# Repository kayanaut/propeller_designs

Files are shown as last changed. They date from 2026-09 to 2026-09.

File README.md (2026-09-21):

# Propeller Designs

A reference collection for propeller and thruster design: what each design type is for, how
to build it, and the geometry tables to build it from. Mostly marine, mostly small.

- [underwater_designs.md](underwater_designs.md) — thirteen marine propulsor types, what
  each is for, its typical parameter ranges, and where its geometry lives
- [aerial_designs.md](aerial_designs.md) — eleven air propeller and rotor types, the same way

## CAD prompts

- [cad/aerial_cad.md](cad/aerial_cad.md) — build briefs for the aerial designs
- [cad/underwater_cad.md](cad/underwater_cad.md) — build briefs for the underwater designs

## In this repo

- [cad/](cad/README.md) — 54 geometry tables across 24 design families, one folder per
  design, each with a `source-geometry.md` saying what data it needs and what has been found
- [cad/CONVENTIONS.md](cad/CONVENTIONS.md) — the datums: face pitch line, generator line,
  rake, skew and camber. The definitions the textbooks leave implicit, and that quietly
  break a blade when you get them wrong
- [formulas.md](formulas.md) — the working equations, each with the datum it assumes
- [cad/tools/](cad/tools/) — regenerate the tables (`make-geometry.py`), check them against
  the briefs' own rules (`check-geometry.py`), build a ducted propeller from them at any
  diameter (`build_ducted_kort.py --diameter 100`), and check an exported mesh is closed
  (`check_stl.py`)
- [projects/toroidal-rov-thruster/](projects/toroidal-rov-thruster/) — one design carried
  all the way through: parametric CAD, geometric checks and OpenFOAM cases, with its
  mistakes left visible

## Geometry creation

- [CadQuery](https://cadquery.readthedocs.io/) — Python parametric CAD on OCCT; the scripting tool the build briefs assume
- [Parametric Propeller CAD Generator](https://github.com/Andre-AH/Parametric-Propeller-CAD-Generator) — FreeCAD, blade count, diameter and angles driven from a spreadsheet
- [bladegen](https://github.com/tallakt/bladegen) — OpenSCAD blade generator
- [OpenVSP](https://github.com/nasa/OpenVSP) — NASA parametric geometry tool with a real propeller component: activity factor, feathering, folding
- [PropCad](https://www.hydrocompinc.com/solutions/propcad/) — marine propeller geometry from chord, thickness, skew and rake distributions
- [B-Series propeller generator](https://www.wageningen-b-series-propeller.com/) — Wageningen B geometry straight to STL or STEP
- [APC geometry files](https://www.apcprop.com/technical-information/file-downloads/) — `.peo` text files with real blade offsets for every APC size
- [UIUC airfoil coordinates](https://m-selig.ae.illinois.edu/ads/coord_database.html) — ~1,600 section coordinate sets; every blade loft starts here

## Data and tools

- [UIUC propeller database](https://m-selig.ae.illinois.edu/props/propDB.html) — measured low-Reynolds propeller performance
- [APC performance data](https://www.apcprop.com/technical-information/performance-data/) — computed curves for every APC size
- [XFOIL](https://web.mit.edu/drela/Public/web/xfoil/) — section polars at the low Reynolds numbers small blades actually run at
- [XROTOR](https://web.mit.edu/drela/Public/web/xrotor/) — lifting-line design and analysis for free-tip and ducted propellers
- [QPROP](https://web.mit.edu/drela/Public/web/qprop/) — propeller and motor as one system, for matching a blade to its drive
- [JBLADE](https://sites.google.com/site/joaomorgado23/downloads) — open-source BEM propeller design, coupled to XFOIL for polars
- [OpenProp](https://www.epps.com/openprop) — GPL lifting-line design code, used for AUV and ROV thrusters
- [JavaProp](https://www.mh-aerotools.de/airfoils/javaprop.htm) — free propeller design and analysis for small aircraft and boats
- [ITTC open water test procedure](https://www.ittc.info/media/9621/75-02-03-021.pdf) — how marine propeller performance is actually measured and reported
- [trimesh](https://trimesh.org/) — watertight and manifold checks on an exported mesh

*Links checked 2026-09-08.*

## Reading the data

Every table says where it came from, in its own header: transcribed from a cited source,
`GENERATED BY` a named script, or `SYNTHETIC` — invented to be dimensionally consistent with
a brief, and never to be mistaken for a real design. Where a source prints something
impossible or omits a table, that is recorded as a `DEFECT:` or `NOT IN SOURCE` note rather
than quietly patched; it is usually the reason the geometry is the way it is.

Nothing here has been physically built and tested, and no performance number in this
repository has been validated against a measurement.

## Licence

Code ([cad/tools/](cad/tools/), `projects/**/source/`) under [MIT](LICENSE); tables, briefs
and documentation under [CC BY 4.0](LICENSE-DATA). Transcribed and vendor material keeps the
terms of its own source and is not relicensed here — each file names it.

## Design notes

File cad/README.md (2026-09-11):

# CAD Models

Briefs: [aerial_cad.md](aerial_cad.md) · [underwater_cad.md](underwater_cad.md).
Datums: [CONVENTIONS.md](CONVENTIONS.md) — pitch line, generator line, rake and camber
definitions the briefs leave implicit. Every CSV repeats them in its own header, so a table
never has to be interpreted from memory.
Models: [underwater/](underwater/) · [aerial/](aerial/), one folder per design, each with a
`source-geometry.md` naming the data it needs and the CSVs holding what has been obtained.
Generated tables come from [tools/make-geometry.py](tools/make-geometry.py) (underwater) and
[tools/make-aerial-geometry.py](tools/make-aerial-geometry.py) — re-runnable, byte-identical,
each with its own rules checker. **The two domains do not share rules:** the 1 mm minimum
trailing-edge thickness is wet-specific and must never be applied to an aerial blade, which
wants a sharp TE. Provenance is marked per requirement: `SOURCED` (published table, cited),
`GENERATED` (published equation), `SYNTHETIC` (built here from the brief's own numbers — never
from a real series), `NOT SOURCED` (missing, with the reason). All 24 designs now have geometry. The five remaining
`NOT SOURCED` entries are real-source gaps a synthetic stand-in does not close — four marine
(B-series ×2, DTMB 4381–4384 offsets, Newton–Rader) and one aerial (NACA 6-series ordinates,
which are tabulated rather than equation-derived).

# **Built:** 
6 of 13 underwater, 0 of 11 aerial. All six are watertight and manifold.

- **[ducted-kort](underwater/ducted-kort/model.stl)** — *meets its brief.* Nozzle ID 250, Ø247
  `Z=4`, clearance 1.500 with zero deviation across the tip chord. Checked against real 19A
  ordinates ([source-geometry.md](underwater/ducted-kort/source-geometry.md)): wall is
  cylindrical over the sweep and the tip is square. Nothing outstanding.
- **[surface-piercing](underwater/surface-piercing/model.stl)** — *fix the planform.* The only
  single unioned solid in the set. Tip is tapered, not a square-cut cleaver. Ø285.6 vs 250.
- **[rim-driven](underwater/rim-driven/model.stl)** — *fix the duct.* Rotor correct and truly
  hubless. Duct is a bare annulus; magnets overlap the ring instead of sitting in pockets.
- **[contra-rotating](underwater/contra-rotating/model.stl)** — *delete one body.* Pair is correct
  and the mirror is genuine. A stray third propeller sits at `z=0` and clashes with the sleeve.
- **[pump-jet](underwater/pump-jet/model.stl)** — **rebuild.** Rotor cuts through the shroud by
  9.5 mm; stator sits inside the rotor, not up- or downstream; built on Y.
- **[supercavitating](underwater/supercavitating/model.stl)** — **rebuild.** Blades are detached —
  a 4.62 mm gap, nothing unioned. Ø297.7 vs 250.

# **Not built**

**underwater:** 
- FPP
- CPP
- Tip-loaded
- Skewed
- Toroidal
- Voith Schneider
- Podded azimuth

**aerial:** 
- Fixed-pitch
- Custom carbon
- Collective pitch
- eVTOL proprotor
- Folding
- Ducted fan
- Coaxial
- Q-tip
- Toroidal
- Serrated
- Cyclorotor.

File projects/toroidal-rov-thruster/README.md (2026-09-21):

# Toroidal ROV thruster

A ducted toroidal-bladed thruster for a small ROV, built around a
[Blue Robotics M200](https://bluerobotics.com/store/thrusters/motors/m200-motor-r1/) motor
and intended for resin printing. This is the repository's one complete design: carried from
parameters through CAD, geometric checks and CFD, with its mistakes left visible.

> **Status: UNVALIDATED.** Nothing here has been printed, and no thrust has ever been
> measured. The CFD numbers below come from a steady MRF run that was stopped before
> convergence, on one mesh, never compared with any measurement. Use them to compare
> options, not to predict performance.

## What is here

| Folder | What it is |
|---|---|
| [`toroidal_rov_prototype2A/thruster_proto2A/`](toroidal_rov_prototype2A/thruster_proto2A/) | The current design, revision **P2A-M2**. Parametric CadQuery source, checks, reports and docs. |
| [`prototype2A_M2_openFOAM/`](prototype2A_M2_openFOAM/) | The OpenFOAM v2412 case for M2, and the archived results of the forward run. |
| [`prototype1D_1B14_openFOAM/`](prototype1D_1B14_openFOAM/) | The earlier 1B-14 case, kept for its baseline (design A) which every later number is compared against. |

## Where it stands

| | |
|---|---|
| Rotor | Constant P/D 0.75 on a true helix, symmetric NACA sections, **no camber** |
| Motor | Blue Robotics M200, flooded, Kv 470, 390 W at 16 V |
| Diameter | ~100 mm envelope; tip clearance 2.13 mm (2.1% of D) |
| CAD gates | All pass — see [`docs/RELEASE_STATUS.md`](toroidal_rov_prototype2A/thruster_proto2A/docs/RELEASE_STATUS.md) |
| CFD, forward | 29.1 N, 0.413 N·m, 130 W, 0.225 N/W at 3000 rpm — **NOT CONVERGED**, stopped at iteration 4467 |
| Cavitation | Lowest rotor wall pressure −180 kPa at the loop apex: vapour predicted shallower than about 8 m |
| Physical test | **None** |

## The known problems

Kept here because they are more instructive than the result:

1. **The pitch datum does not match the repository's own convention.** `CONVENTIONS.md`
   specifies face pitch; the rotor applies the angle to the chord line. Its `P/D = 0.75` is
   therefore not comparable with a Ka-series `P/D = 0.75`.
2. **The sections have no camber.** A symmetric section must be tilted to make lift, which
   is the direct cause of the −180 kPa suction peak at the loop apex.
3. **Tip clearance is 2.1% of D**, against 0.6% in this repository's ducted-kort brief.
4. **The duct is an invented foil**, not the 19A ordinates the repository has transcribed
   and committed.
5. **No baseline.** Nothing has been built to a published design and measured, so there is
   nothing to calibrate any of this against.

The datums these depart from are defined in
[cad/CONVENTIONS.md](../../cad/CONVENTIONS.md), and the working equations in
[formulas.md](../../formulas.md).

## Running it

Build the CAD (needs CadQuery):

```bash
cd toroidal_rov_prototype2A/thruster_proto2A
python3 source/run_all.py            # builds every part and runs every gate
python3 source/export_cfd.py         # writes the CFD surfaces
```

The numeric blade gates run without a CAD kernel:

```bash
python3 source/rotor.py --check-only
```

The vendor motor STEP is not in this repository. Without it the build falls back to a
parametric M200 and skips the interface cross-check; to get it, run
[`fetch_m200_cad.py`](fetch_m200_cad.py).

For the CFD, see [`prototype2A_M2_openFOAM/RUN_GUIDE.md`](prototype2A_M2_openFOAM/RUN_GUIDE.md).
Solves take hours on a laptop.

## What would move this forward

1. Print the hub fit coupon and check it on a real M200.
2. Build a bollard rig and measure thrust against rpm. Any measurement beats none.
3. Reduce the apex suction peak (lighter loading, or more thickness/chord there) and
   recheck the minimum pressure.
4. The reverse run, and a run near 3300 rpm for the 35 N target.

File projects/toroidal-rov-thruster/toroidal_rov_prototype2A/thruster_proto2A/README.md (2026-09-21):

# Toroidal ROV thruster — P2A-M2

**Parametric fit-test revision of P2A, built around the Blue Robotics M200 motor. Fit and assembly testing only.**

> **UNVALIDATED.** Nothing here has been printed and no thrust has been measured.
> The CFD result quoted anywhere in this package comes from a run that was stopped
> before convergence and has never been compared with a measurement.

M2 starts from the P2A-M1 package. The blade, duct and support concept are unchanged from M1. The motor interface is rebuilt around the real M200: its drawing and the vendor STEP.

| Area | M1 | M2 |
|---|---|---|
| Motor | Placeholder outrunner (can Ø50) | Blue Robotics M200: can Ø36 × 29, base Ø40 × 25.5, Kv 470, 390 W at 16 V |
| Rotor to motor | 4× M3 on a 16 mm circle, plain pilot bore | 2× M3 × 25 into the M200 rotor face (Ø19.05 circle); collar counterbore; D-bore on the shaft flat for positive drive |
| Motor vents | — | Two Ø4.5 passages through the hub and clamp ring, lined up with the M200's two vents |
| Shroud | Bore sized from the can only | Bore is a slide fit on the M200 base, which centres the motor on the duct; 2.3 mm clearance to the spinning can |
| Cable | Rear centre hole | Radial hole with strain-relief boss where the M200 cable leaves its base |
| Rear plate | 4× M3 on a placeholder pattern | 4× M3 × 8 into the M200 base inserts (21.2 mm square), counterbored; drain hole |
| Coupon | Plain bores | Copies of the real hub interface (collar, round bore, D-bore) plus M3 holes |
| Checks | Placeholder motor | Vendor STEP cross-checked against the parameters; zero overlap with the vendor motor; vent, collar, flat and screw-depth checks |

The blade is unchanged from M1: constant P/D 0.75 on a true helix, NACA sections, apex solved to the 100 mm envelope. Compared with M0, M1 fixed the pitch law (M0 ran from P/D 0.55 to 7.8), thinned the sections and tightened the tip gap from 3 to 2 mm.

**Forward thrust:** the rotor turns counter-clockwise seen from the inlet, and water leaves past the motor support.

## Start here

1. `docs/ROADMAP.md` shows where the project stands and what comes next. `docs/RELEASE_STATUS.md` lists every check.
2. Look at `previews/` (assembly, section, axial, rotor, exploded) and `previews/blade_distribution.png`.
3. Open `exports/assembly_with_reference_hardware.step` in a CAD viewer to see the parts on the vendor M200 model.
4. Print `hub_fit_coupon` first, in the resin and orientation you'll use for the rotor, and test it on a real M200. See `docs/COUPON.md`.

## Folder contents

| Folder | Contents |
|---|---|
| `source/` | `parameters.json`; `rotor.py` (blade and hub), `build.py` (other parts), `motor_step.py` (vendor STEP alignment and cross-check), `hardware.py`, `export_cfd.py`; checks and packaging |
| `exports/` | STEP, STL, 3MF and BREP for the four printed parts; `REFERENCE_*` meshes; assembly STEPs; `cfd/` surfaces for OpenFOAM |
| `hardware/` | Aligned M200, clamp ring and screws; `vendor/` holds Blue Robotics' original M200 CAD download |
| `previews/` | Actual-CAD images and the blade section chart |
| `reports/` | Motor interface, blade table, build, mesh, clearance, stack and self-interference reports, logs |
| `docs/` | Roadmap, release status, assembly, hardware list, resin print preparation, coupon, parameters, open inputs |
| `slicer/`, `machine_output/` | Unconfirmed resin process inputs; no fabricated slicer output |

The OpenFOAM case for this revision is `../../prototype2A_M2_openFOAM/`.

## Printable parts

Print only these: `rotor`, `duct_full`, `motor_support`, `hub_fit_coupon`. Never print `REFERENCE_*` files as working parts.

All coordinates are **millimetres** and the rotation axis is **+Z**; water enters at −Z. STEP and STL keep assembly coordinates. Each 3MF declares millimetres and moves its part onto z = 0 without scaling.

## Edit and rebuild

Use Python 3.12 with the packages in `requirements.txt`. Run from this folder:

```bash
python -m pip install -r requirements.txt
python source/rotor.py --check-only    # blade gates in under a second, no CAD
python source/run_all.py               # motor check, build, export, render and check everything
python source/package_release.py       # release status, index, manifest and ZIP
python source/export_cfd.py            # CFD surfaces, copied into the OpenFOAM case
```

A rebuild overwrites `exports/`, `reports/` and `previews/`. `motor_step.py` stops the build if the vendor M200 STEP and `parameters.json` disagree by more than 0.1 mm or 0.5°. `package_release.py` refuses to package unless every gate passes, and names the ZIP after the revision. Parameter meanings are in `docs/PARAMETERS.md`.

No CFD result, structural analysis, balance test, submerged test or calibrated resin profile is included yet.

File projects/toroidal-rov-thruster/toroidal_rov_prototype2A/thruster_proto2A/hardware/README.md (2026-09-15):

# Hardware references — not for printing

- `REFERENCE_M200_rotating` / `REFERENCE_M200_stationary`: Blue Robotics M200 standard (BR-101376), from the vendor STEP hardware/vendor/M200_STANDARD_BR-101376_PUBLIC.STEP, placed in the thruster frame (rotor face at z = 16 mm, cable toward 60°). `vendor/` holds Blue Robotics' original download. `reports/motor_interface.json` compares the STEP with `source/parameters.json`.
- `REFERENCE_clamp_ring`: metal ring Ø27 × 1.5 mm under the screw heads, with 2 screw holes and 2 vent holes aligned with the motor vents. It spreads the clamp load so the resin hub does not crack or creep under the heads.
- `REFERENCE_hub_screws`: 2× M3 × 25 socket head cap screws into the M200 rotor face (5 mm maximum depth; this design engages 4 mm).

## Load path

- **Torque:** M200 shaft D-flat and the 2 face screws (clamp friction plus shank bearing) → resin hub → loops.
- **Forward thrust** (jet toward the support) pulls the rotor away from the motor: the 2 face screws carry it in tension, and the M200 base screws carry it into the rear plate.
- **Reverse thrust** presses the hub onto the rotor face and the base onto the rear plate.
- The collar only locates; the hub seats on the rotor face. `reports/hardware_stack.json` checks screw engagement, shaft tip and collar clearance.

## Fasteners

Do **not** use threadlocker. Blue Robotics warns that most threadlockers attack the polycarbonate in their motors and make it brittle. Tighten snugly and recheck screw tension after the first soak, because resin under a clamp relaxes. The base takes 4× M3 × 8 screws with no more than 6 mm thread engagement.

The M200 is designed to run flooded. The support shroud is a flow-through guard, not a seal; keep the motor vents and cooling slots open.

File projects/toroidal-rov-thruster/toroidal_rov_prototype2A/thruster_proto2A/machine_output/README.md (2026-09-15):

# Machine output pending

No G-code, resin exposure file, powder-bed job, or calibrated slicer project is supplied because the printer, process, material and hardware interface are unconfirmed. Generating files for an arbitrary machine would not satisfy the manufacturing requirement.

Geometry STEP/STL/3MF files are supplied in `exports/`. Store the actual machine project/output here only after the inputs and layer inspection are complete. This folder is intentionally not presented as a passed release gate.

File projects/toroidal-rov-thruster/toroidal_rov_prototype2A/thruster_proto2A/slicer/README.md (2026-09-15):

# Slicer handoff (resin)

No printer, resin or slicer profile is selected. `process_inputs.json` lists the unknown inputs. `conditional_resin_starting_points.json` is a human-readable starting record for a generic MSLA printer, not an importable profile or an authorisation to print.

Open only the four printable 3MFs (`rotor`, `duct_full`, `motor_support`, `hub_fit_coupon`). Select the resin maker's profile for your printer and set the orientations from `docs/PRINT_PREPARATION.md`. Inspect every layer for islands, suction cups and support access, then save the real slicer project here. Never print `REFERENCE_*` files as working parts.

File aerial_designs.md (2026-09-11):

# Aerial Designs

Eleven air propeller and rotor types, what each is for, and where it lives in this repo. Ranges are
**typical of the design class**, not the parameters of our models — those are in the
[build briefs](cad/aerial_cad.md), and are deliberately not repeated here.

None is built yet; all eleven have source geometry in [cad/](cad/README.md). Model links are marked
*(authoritative)* where the source publishes real offsets, and *(third-party)* where it is an
unvalidated user upload — useful to look at, not to build from.

---

- **Fixed-pitch (low-Re)** — Moulded or carbon blade cut for one rpm; the baseline, and the only class
  with public measured data across most sizes. **One operating point: efficiency falls away either
  side of it, and at these Reynolds numbers the section does most of the work.**
  *Use for* fixed-rpm multirotors and any airframe with one dominant condition.
  Z 2–3 · D 5–15 in · P/D 0.4–0.8 · tip Re 50k–200k.
  → [brief](cad/aerial_cad.md) · [geometry](cad/aerial/fixed-pitch/) — **real APC 10×5E mould
  geometry, 51 stations**, plus UIUC Clark-Y and Eppler E63 coordinates ·
  [UIUC propeller database](https://m-selig.ae.illinois.edu/props/propDB.html) *(authoritative — measured performance)* ·
  [APC geometry files](https://www.apcprop.com/technical-information/file-downloads/) *(authoritative — mould offsets)* ·
  also in water: [marine FPP](underwater_designs.md)

- **Custom carbon blade** — Planform and pitch made to order for one airframe and motor pairing.
  **No measured data exists for a one-off**, so it lives or dies on the design-point solve, and a
  thin sharp-TE carbon blade is less forgiving of a bad pitch choice than a moulded plastic one.
  *Use for* a known thrust, rpm and forward speed you can actually solve for.
  t/c 12% root to 7% tip · sharp trailing edge · cylindrical clamped shank.
  → [brief](cad/aerial_cad.md) · [geometry](cad/aerial/custom-carbon/) — the chord/twist CSV is the
  interface; replace it with a JavaProp/QPROP/XROTOR solve ·
  [Mejzlik](https://www.mejzlik.eu/) ·
  [propeller-FreeCAD](https://github.com/Rigel-Alves/propeller-FreeCAD) *(third-party)*

- **Collective pitch** — A variant of the custom carbon blade: pitch actuated in flight, so thrust
  changes without changing rpm. **Hub mass, linkage wear and a lot of moving parts** bought for
  response time. *Use for* aerobatic and fast-response airframes where rpm-change lag is the limit.
  Pitch ±25° · shank ~8 mm · two bearings per grip.
  → [brief](cad/aerial_cad.md) · [geometry](cad/aerial/collective-pitch/) — bearing options ·
  [T-Motor VP props](https://store.tmotor.com/categorys/manual-variable-pitch-polymer-propeller) ·
  [Variable-pitch propeller](https://grabcad.com/library/variable-pitch-reverse-thrust-propeller) *(third-party)*

- **eVTOL proprotor** — Rigid blade with no cyclic that must work as a rotor in hover and a propeller
  in wing-borne cruise. **It is optimal in neither**: the blade is a compromise, and the blend weight
  between the two design points is the entire design problem.
  *Use for* tiltrotor and tilt-wing conversions. High twist (XV-15 runs −40°) · tip Mach ≤ 0.55.
  → [brief](cad/aerial_cad.md) · [geometry](cad/aerial/evtol-proprotor/) — **real XV-15 reference
  planform**, plus hover and cruise twist with a live blend weight ·
  [Tilt-wing proprotor optimisation](https://www.sciencedirect.com/science/article/pii/S1270963823007319) ·
  [Tiltrotor UAV](https://grabcad.com/library/tiltrotor-uav-1) *(third-party)*

- **Folding blade** — Blades fold back when unpowered to cut drag in winged cruise. **Hinge wear and
  a deployment that depends on mass distribution**: the blade's centre of mass must sit outboard of
  the hinge pin or it never opens. *Use for* VTOL fixed-wing craft with lift rotors that stop.
  Hinge pin Ø ~3 mm · fold range to ~175° · running-clearance fit, not line-to-line.
  → [brief](cad/aerial_cad.md) · [geometry](cad/aerial/folding/) — hinge fit classes ·
  [T-Motor folding props](https://store.tmotor.com/categorys/folding-carbon-fiber-propeller) ·
  [Folding propellers (STL)](https://www.printables.com/model/89982-folding-propellers-for-rocket-drones) *(third-party)*

- **Ducted fan** — Rotor in a close-fitting duct; high static thrust for the disc area. **The duct's
  gain fades with forward speed and costs weight and wetted area**, and tip clearance dominates
  performance at small scale. *Use for* high static thrust in a constrained diameter.
  Hub ratio 0.4–0.5 · tip clearance ~0.5% D · stator V ≥ 2Z for tone cut-off.
  → [brief](cad/aerial_cad.md) · [geometry](cad/aerial/ducted-fan/) — duct wall cylindrical across the
  rotor plane, rotor tip pinned to the clearance ·
  [Schübeler](https://www.schubeler.com/home/) ·
  [EDF unit, 5 blade](https://grabcad.com/library/edf-ducted-fan-unit-2-5inch-5-blade) *(third-party)* ·
  also in water: [Kort nozzle](underwater_designs.md)

- **Coaxial contra-rotating** — Two rotors on one axis turning opposite ways; cancels torque and packs
  two discs into one footprint. **The lower rotor works in the upper's wake and the pair falls well
  short of double the thrust** — induced power climbs steeply as spacing shrinks.
  *Use for* footprint-limited airframes, sized against what a pair actually delivers.
  Spacing 0.1–0.2 D · lower rotor pitched up for the upper's downwash.
  → [brief](cad/aerial_cad.md) · [geometry](cad/aerial/coaxial/) — lower-rotor pitch from a
  first-order actuator-disc estimate ·
  [Coaxial swashplateless UAV](https://arxiv.org/abs/2511.04251) ·
  [Coaxial propeller V2](https://grabcad.com/library/coaxial-propeller-v2-1) *(third-party)* ·
  also in water: [marine CRP](underwater_designs.md)

- **Tip device (Q-tip)** — Tip curled aft as an inverted winglet; the certified, conservative way to
  break up the tip vortex. **It shrinks the swept disc** — a few percent of radius traded for ground
  clearance and tip noise. *Use for* noise or clearance limits on an otherwise settled blade.
  Bend from r/R ~0.92 · ~75° aft · bend radius small against the blade.
  → [brief](cad/aerial_cad.md) · [geometry](cad/aerial/q-tip/) — bend path reporting projected versus
  developed diameter, which is the trade ·
  [Hartzell Q-Tip](https://hartzellprop.com/products/top-prop/piper/twin-comanche-2-blade-q-tip/) ·
  [Swept profile blade](https://grabcad.com/library/swept-profile-propeller-blade) *(third-party)*

- **Toroidal** — Looped blade with no free tip. **Redistributes tonal noise rather than reliably
  removing it, and measured examples pay for it in torque** — the marketing and the measurements
  disagree, so read the second link before committing.
  *Use for* cases where shifting tones out of the annoying band is worth a torque penalty.
  Two or three loops · no free tip · chord scheduled along the loop path.
  → [brief](cad/aerial_cad.md) · [geometry](cad/aerial/toroidal/) — Catmull-Rom loop path, implemented
  independently because the generator below is GPL-3.0 ·
  [MIT Lincoln Laboratory](https://www.ll.mit.edu/partner-us/available-technologies/toroidal-propeller) ·
  [Measured against conventional blades](https://acta-acustica.edpsciences.org/articles/aacus/full_html/2026/01/aacus260084/aacus260084.html) ·
  [Toroidal generator](https://github.com/RaulBejarano/Ultimate-Toroidal-Propeller-Generator) *(authoritative — GPL-3.0, check before reuse)* ·
  also in water: [Sharrow loop](underwater_designs.md)

- **Serrated edge** — Owl-inspired saw-tooth edges that break up edge noise without changing the
  planform. **Broadband gain is modest and manufacturing is harder**, and the serration must follow
  the blade's own surface or it bites deeper at the root than the tip.
  *Use for* a retrofit noise fix that leaves performance essentially alone.
  Amplitude ~5% and wavelength ~10% of local chord · applied outboard of r/R 0.5.
  → [brief](cad/aerial_cad.md) · [geometry](cad/aerial/serrated/) — amplitude scheduled off local
  chord at every station ·
  [Serrated TE for drone noise](https://www.sciencedirect.com/science/article/abs/pii/S0003682X25005171)
  *No model link:* serrations are applied to a base blade, so there is no separate model to point at.

- **Cyclorotor** — Vertical blades on a drum with cyclic pitch; instant thrust vectoring at low tip
  speed. **Structural and bearing loads are severe and efficiency trails a conventional rotor** —
  this is a research configuration, not something you buy.
  *Use for* experimental craft where vectoring response is the objective.
  4–6 blades · c/R ~0.35 · pitch ±35° · symmetric section.
  → [brief](cad/aerial_cad.md) · [geometry](cad/aerial/cyclorotor/) — NACA 0015 generated exactly from
  the published equation ·
  [Hover performance study](https://sites.utexas.edu/sirohi/files/2017/07/010_parsons07_jahs.pdf)
  *No model link:* no production hardware exists to model.

---

*Scope: air propellers and rotors for UAV and eVTOL scale, plus the full-scale designs (Q-tip,
proprotor) that the small-scale versions are derived from. Helicopter main rotors with cyclic and
flapping hinges are a different discipline and are out of scope. Links checked 2026-09-08.*

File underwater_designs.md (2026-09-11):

# Underwater Designs

Thirteen marine propulsor types, what each is for, and where it lives in this repo. Ranges are
**typical of the design class**, not the parameters of our models — those are in the
[build briefs](cad/underwater_cad.md), and are deliberately not repeated here.

`built` marks a model that exists as geometry in [cad/](cad/README.md); all thirteen have source
geometry. Model links are marked *(authoritative)* where the source publishes real offsets, and
*(third-party)* where it is an unvalidated user upload — useful to look at, not to build from.

---

- **Fixed-pitch (FPP)** — Solid cast blade at one pitch; the marine baseline. Cheapest thrust per
  unit cost with nothing to fail, but **one design point only, and astern means reversing the shaft**.
  *Use for* any vessel with a single dominant operating condition. Z 3–6 · P/D 0.6–1.4 · BAR 0.4–0.8.
  → [brief](cad/underwater_cad.md) · [geometry](cad/underwater/fixed-pitch/) — real DTMB 4119 as a
  substitute; the B-series tables themselves are copyrighted and still open ·
  [B-series generator](https://www.wageningen-b-series-propeller.com/) *(authoritative — emits STL/STEP)* ·
  also in air: [aerial fixed-pitch](aerial_designs.md)
  *Available:* Wärtsilä, Kongsberg, MAN Alpha, MMG; small-craft stock props from ~$100.

- **Controllable-pitch (CPP)** — Hub mechanism rotates the blades in service, so thrust and reverse
  are set without reversing shaft rpm. **The oversized hub costs 1–3% efficiency**, plus an oil
  system, higher capex and real maintenance. *Use for* vessels that must hold station, tow, and
  transit. Z 4–5 · hub 0.25–0.32 D · pitch travel ~±35°.
  → [brief](cad/underwater_cad.md) · [geometry](cad/underwater/controllable-pitch/) — **real SVA
  Potsdam VP1304 blade offsets at Ø250 mm**, the repo's best measured data ·
  [Wärtsilä CPP](https://www.wartsila.com/marine/products/propulsors-and-gears/propellers/wartsila-controllable-pitch-propeller-systems)
  *Available:* Wärtsilä, Kongsberg, MAN Alpha VBS, Berg, Schottel. Effectively unavailable below
  small-workboat size.

- **Tip-loaded (Kappel / CLT)** — Tip bent into an end plate — suction side on a Kappel, pressure
  side on a CLT — to hold loading out at the tip instead of spilling it over. **Gains are wake- and
  scale-dependent so they vary by hull, tips are fragile, and it carries a price premium.**
  *Use for* full-form hulls where a few percent at one speed justifies the premium. Otherwise a
  conventional Z 4–6 blade.
  → [brief](cad/underwater_cad.md) · [geometry](cad/underwater/tip-loaded/) — synthetic tip-rake law ·
  [Tip rake on Kappel propellers](https://www.mdpi.com/2077-1312/11/4/748)
  *No model link:* both forms are proprietary (MAN Alpha Kappel, SISTEMAR CLT) and no tip-rake law
  is published. *Available:* SISTEMAR CLT; MAN Alpha Kappel FP.

- **Ducted propeller / Kort nozzle** `built` — Propeller inside a fixed accelerating nozzle. Big
  bollard-pull gain when heavily loaded, but **duct drag penalises free-running above ~10 kn, it
  collects debris, and tip-gap losses get proportionally worse as diameter shrinks**.
  *Use for* tugs, trawlers, ROV thrusters. Kaplan-type blade · tip clearance ≤1% D · L/D 0.5.
  → [brief](cad/underwater_cad.md) · [geometry](cad/underwater/ducted-kort/) — **real 19A nozzle
  ordinates and Ka-series sections** · [built model](cad/README.md): meets its brief, clearance 1.500
  with zero deviation · [Kort nozzle](https://www.wartsila.com/encyclopedia/term/kort-nozzle) ·
  also in air: [ducted fan](aerial_designs.md)
  *Available:* Schottel, Wärtsilä, Kongsberg. Vehicle scale — Blue Robotics, Tecnadyne, Copenhagen Subsea.

- **Pump-jet** `built` — Rotor and stator fully enclosed in a long **decelerating** shroud; a variant
  of the ducted propeller inverted for quiet running. Suppresses tip-vortex cavitation, at the cost of
  **weight, length and complexity that only pay where acoustic signature dominates**.
  *Use for* submarines and torpedoes. Rotor Z ~7 · stator V ≥ 2Z · tip gap ~0.2% D.
  → [brief](cad/underwater_cad.md) · [geometry](cad/underwater/pump-jet/) — note 19A is the **wrong**
  duct family here; this one decelerates · [built model](cad/README.md): **needs rebuild**, the rotor
  passes through the shroud ·
  [Pump-jets vs. propellers](https://www.twz.com/31708/veteran-sonarman-explains-why-pump-jets-are-superior-to-props-on-modern-submarines)

- **Rim-driven (hubless)** `built` — Blades carried on a motor-rotor ring with no hub and no shaft;
  the ring runs inside a stator built into the duct. **Gap viscous losses and low-Reynolds penalties
  bite hard at small scale; bearing wear, sealing and magnet corrosion set service life; premium price.**
  *Use for* compact, retractable or low-signature installations where the shaft line is the problem.
  → [brief](cad/underwater_cad.md) · [geometry](cad/underwater/rim-driven/) — blade thickness runs
  **inverted**, thickest at the ring, because the structural root is at the tip radius ·
  [built model](cad/README.md): rotor correct, duct and magnet pockets unmodelled ·
  [SCHOTTEL RimThruster](https://www.schottel.de/en/portfolio/products/product-details/srt-schottel-rimthruster)
  *Available:* Schottel SRT 200–800 kW; Copenhagen Subsea at vehicle scale.

- **Contra-rotating (CRP)** `built` — Two coaxial propellers turning opposite ways recover the swirl energy a
  single screw sheds into its wake. **Concentric shafting, bearings and seals raise cost and add
  blade-interaction noise.** *Use for* small craft where the drive already exists as a package.
  Aft disc ~0.9 D of the forward one · blade counts coprime (3+4, 4+5).
  → [brief](cad/underwater_cad.md) · [geometry](cad/underwater/contra-rotating/) — aft-disc pitch is a
  first-order estimate and **needs a lifting-line run**, not a table ·
  [built model](cad/README.md): pair correct, delete the stray third propeller ·
  [Brunvoll CRP](https://www.brunvoll.no/products/crp-contra-rotating-propellers) ·
  also in air: [coaxial](aerial_designs.md)
  *Available:* Volvo Penta IPS and Duoprop, Mercury Bravo Three — genuinely off-the-shelf at small scale.

- **Surface-piercing (SPP)** `built` — Cleaver blades run half out of the water, ventilating instead
  of cavitating; cuts appendage and wetted drag on planing hulls. **Once-per-revolution blade loading,
  heavy vibration, poor low-speed thrust and expensive drive hardware.**
  *Use for* fast planing craft above ~35 kn. Wedge sections · high P/D · articulating drive leg.
  → [brief](cad/underwater_cad.md) · [geometry](cad/underwater/surface-piercing/) — synthetic cleaver
  outline · [built model](cad/README.md): tip is tapered where a cleaver is square ·
  [Arneson surface drives](https://twindisc.com/arneson/)
  *No model link:* cleaver outlines are commercial (Rolla, Mercury Bravo) and unpublished.
  *Available:* Twin Disc Arneson ASD, France Hélices, Rolla.

- **Supercavitating** `built` — Wedge sections force a vapour cavity off the leading edge that closes
  behind the blade, so the collapse never touches metal. **The geometry is poor below its design
  speed**, which makes recording that speed part of the design rather than a footnote.
  *Use for* craft that live above ~45 kn and nowhere else. Z ~3 · P/D 1.4–1.8 · max thickness at the TE.
  → [brief](cad/underwater_cad.md) · [geometry](cad/underwater/supercavitating/) — synthetic wedge,
  design speed recorded as an explicit assumption · [built model](cad/README.md): **needs rebuild**,
  blades are detached from the hub ·
  [Supercavitating propellers](https://www.globalsecurity.org/military/systems/ship/systems/propellers-supercavitating.htm)
  *No model link:* the Newton–Rader (1961) section series is paywalled.

- **Skewed blade** — Blades swept back along the disc so each section enters the wake peak in turn;
  delays and quiets cavitation. Now the default merchant stern propeller, but **higher root stress,
  weaker astern, and more expensive pattern-making and finishing**.
  *Use for* any hull with a non-uniform wake — which is most of them. Z 4–7 · tip skew 30–70° · mild rake.
  → [brief](cad/underwater_cad.md) · [geometry](cad/underwater/skewed/) — the real DTMB 4381–4384
  series at 0/36/72/108° tip skew ·
  [Skew and tonal noise](https://www.sciencedirect.com/science/article/abs/pii/S0029801823006029) ·
  [PropCad](https://www.hydrocompinc.com/solutions/propcad/) *(authoritative — commercial parametric tool)*
  *Available:* a standard offering, not a specialty, from every large propeller OEM.

- **Loop / toroidal (Sharrow)** — Each blade closes into a loop with no free tip. Strong gains through
  the mid range, but they **converge with a well-matched conventional prop at wide-open throttle, and
  it costs much more blade area and friction, weight and money**.
  *Use for* mid-range cruise and noise, not top speed. Typically three loops · cast or 5-axis machined.
  → [brief](cad/underwater_cad.md) · [geometry](cad/underwater/toroidal/) — synthetic loop path ·
  [Sharrow Marine](https://www.sharrowmarine.com/prop) ·
  [Marine toroidal blades](https://grabcad.com/library/e-foil-and-marine-toroidal-propeller-blades-1) *(third-party)* ·
  also in air: [aerial toroidal](aerial_designs.md)
  *Available:* Sharrow with Yamaha Precision Propellers; VEEM licence for inboards up to 5 m.

- **Voith Schneider (cycloidal)** — Vertical foils on a rotating disc with cyclic pitch; full thrust
  vectoring with no rudder and no reversing. **Lower transit efficiency, deep draught, mechanically
  complex, expensive and effectively single-source.**
  *Use for* tugs and ferries where manoeuvring dominates and transit speed does not.
  4–6 foils · disc speed held constant · thrust set by eccentricity.
  → [brief](cad/underwater_cad.md) · [geometry](cad/underwater/voith-schneider/) — NACA 0016 generated
  exactly from the published equation ·
  [Voith-Schneider Propulsor](https://www.wartsila.com/encyclopedia/term/voith-schneider-propulsor-(vsp)-cycloidal-propeller) ·
  [VSP kinematics tutorial](https://grabcad.com/tutorials/voith-schneider-propeller-cycloidal-rotor-pitch-control-catia-dmu-kinematics-tutorial) *(third-party)*
  *Available:* Voith Turbo, single source.

- **Podded azimuth thruster** — Motor in a submerged steerable pod driving a fixed-pitch propeller
  directly; gearless, steers through 360°. **Pod and strut drag, slip rings and bearings, high capex,
  and any underwater repair means docking the ship.**
  *Use for* cruise ships, icebreakers, DP vessels — anything where manoeuvring and layout freedom pay
  for the capex. Puller or pusher · pod Ø ~0.5 D · pod length ~2.5 D.
  → [brief](cad/underwater_cad.md) · [geometry](cad/underwater/podded-azimuth/) — pod fairing and
  strut section · [ABB Azipod](https://new.abb.com/marine/systems-and-solutions/azipod)
  *Available:* ABB Azipod ~1–22 MW; Kongsberg Azipull, Schottel SRP, Wärtsilä steerable thrusters.

---

*Scope: propulsors in production or serious commercial development, marine and underwater. Waterjets,
tunnel thrusters and bolt-on energy-saving devices are propulsion but not propellers, and are out of
scope. Vendor and configuration data from the working notes in `_work/designs.md`. Links checked
2026-09-08; the CAESES B-series article previously cited here has been dropped — it describes the
design process but publishes no geometry.*

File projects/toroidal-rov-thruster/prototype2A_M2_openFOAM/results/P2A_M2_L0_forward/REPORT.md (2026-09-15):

# Prototype 2A-M2 L0 run

Steady MRF, k-omega SST, bollard (still water), seawater, 3000 rpm, forward rotation. Generated by `scripts/convergence_report.py`.

## Mesh and geometry

- Cells 2475440; max non-orthogonality 69.941867; max skewness 3.5625026; checkMesh Mesh OK
- Rotor STL sha256 `41cb99b7f16c4ab160fbda2781051b03a50ae78090a41eed5dfa028eb70c7869`; see geometry/cfd_geometry.json

## Result

```
Iterations: 4460; omega -314.159 rad/s about +x; averages over the last 3000 iterations (6 batches of 500)

  Quantity                                 Mean   95% +/-    (%)  drift %  window change %  peak-to-peak %
  Assembly Fx (N)                        -29.14     0.572   1.96     0.35             0.79           38.22
  Rotor Fx (N)                           -17.86     0.544   3.04     0.88
  Stator Fx, duct + support (N)          -11.28     0.272   2.41     0.50
  Rotor Mx (N m)                        +0.4132    0.0104   2.52     2.26             4.10           30.48
  Shaft power -omega*Mx (W)              +129.8      3.27   2.52     2.26
  Thrust/power -Fx/P (N/W)              +0.2254   0.00548   2.43     1.92
  Flow through rotor (L/s)               +18.06       0.1   0.55     0.11             1.39            5.46
  Min wall pressure, rotor (kPa)         -179.8      2.79   1.55     0.16
  Min wall pressure, stator (kPa)        -96.14      2.81   2.92     0.56

  Assembly force -29.138 N: thrust 29.138 N toward -x
  Shaft power +129.8 W: rotor torque opposes rotation - rotor drives the water
  Jet +x (bellmouth intake, as designed); force direction consistent with the jet
  residual Ux      final 4.52e-03  dropped 2.4 decades  change over last window 0.00 decades
  residual Uy      final 7.92e-03  dropped 2.1 decades  change over last window 0.00 decades
  residual Uz      final 7.71e-03  dropped 2.1 decades  change over last window 0.01 decades
  residual k       final 1.56e-03  dropped 2.8 decades  change over last window 0.00 decades
  residual omega   final 2.69e-04  dropped 1.8 decades  change over last window 0.01 decades
  residual p       final 2.99e-05  dropped 4.5 decades  change over last window 0.01 decades
  Cavitation, rotor: mean min wall pressure -179.8 kPa gauge (worst -249.5); absolute at 1.0 m depth -68.5 kPa vs vapour 2.34 kPa; needs > 8.0 m depth
  Cavitation, stator: mean min wall pressure -96.1 kPa gauge (worst -139.8); absolute at 1.0 m depth 15.2 kPa vs vapour 2.34 kPa; clear
  y+ rotor  min 1.16  max 158.7  mean 30.4
  y+ stator min 0.09  max 371.7  mean 43.8

VERDICT: NOT CONVERGED
```

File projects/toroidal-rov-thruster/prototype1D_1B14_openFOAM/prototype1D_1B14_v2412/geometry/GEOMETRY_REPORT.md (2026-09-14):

# Prototype 1B-14 rotor geometry (design B: front-opening loops)

Generated by `scripts/make_geometry.py`. Re-running it rewrites every file in this folder.

## History

The recovered `prototype1B_rotor.stl` could not be repaired into a valid blade:

- the loop legs converge into a folded tip: path bend radius 0.04 mm under a 20 mm chord, legs closer than one chord beyond r = 40 mm, 1604 self-intersecting triangle pairs;
- the roots twist about 70 deg within 2 mm and the end caps sit 0.11 mm off the hub;
- all four shells were wound inside out and the envelope reached 111 mm;
- adjacent blades overlapped each other at r = 14-25 mm.

Design A (legs stacked axially) replaced it and ran an L0 baseline, archived in `results/designA_stacked_loops_L0/`. Design B, below, opens each loop in the front view like the reference toroidal rotor. Both are SYNTHETIC designs built from the same design parameters, not the recovered shape.

## Parameters

| Parameter | Value | Source |
|---|---:|---|
| Blades | 3 | design json |
| Hub diameter x length | 28.0 x 30.0 mm | design json |
| Root radius (generator line) | 15.2 mm | design json |
| Apex radius (generator line) | 46.03 mm, solved to fit the 100 mm envelope (design r_outer 47.8 mm) | this script |
| Chord root / apex | 12.5 / 19.0 mm | design json |
| Section | NACA 00xx, t/c 0.16 outboard, 0.20 at root | design json (foil_t, root_load) |
| Skew at apex | 7.0 deg, back from rotation | design json |
| Loop axial rise (apex aft of leading root) | 11.5 mm | DOE 1B-14 |
| Loading / pitch scale | 1.0 | DOE 1B-14 |
| Face pitch | 58.38 mm (P/D 0.584), constant | 2 pi r_outer tan(11.0 deg) x loading |
| Second-leg offset | 24.0 mm at r = 20.0 mm, 35.0 deg from +theta toward +z (60 deg from the chord line): +56.3 deg, +13.77 mm | this script |
| Front-view loop opening | 56.3 deg | this script |
| Apex turn radius / turn starts at | 23.65 mm / r = 22.38 mm | this script |
| Chord orientation | on the pitch helix along the legs, normal to the path across the apex (max chord-tangent cosine 0.90) | this script |
| Trailing edge thickness | 0.40 mm | repo rule 1 mm at D 250, scaled |
| Root flare over last 3.0 mm | +50% thickness, +15% chord | modelled fillet |
| closure_bias | not used | |

## Printed hub (STEP only, SYNTHETIC - confirm against the shaft)

- Ring: outer diameter 28 mm, inner diameter 22 mm; blade roots end inside this wall (blade r_min 11.50 mm).
- 3 spokes, 3 mm wide, to a bushing of outer diameter 16 mm.
- Internal spline: 12 teeth, major diameter 12.0 mm, minor diameter 10.5 mm.
- The CFD STL keeps a closed hub: the shaft and insert fill it, and open spoke passages would need their own mesh study.

## Checks

| Check | Result | Limit |
|---|---:|---|
| Envelope radius (STL) | 49.91 mm | <= 50.0 mm |
| Folded stations | 0 | 0 |
| Minimum path bend radius | 12.62 mm | > half thickness |
| Root ends inside hub | r <= 12.93 mm | <= 13.5 mm |
| Blade clear of printed hub pocket | r_min 11.50 mm | >= 11.5 mm |
| Root footprint margin to hub ends | 1.89 mm | >= 0.5 mm |
| Leg-to-leg gap | 15.79 mm | >= 2 mm |
| Blade-to-blade gap | 7.89 mm | >= 2 mm |
| Blade clash volume | 0 mm3 | 0 |
| Solids after fuse | 1 | 1 |
| STL closed / consistent / parts | True / True / 1 | True / True / 1 |
| STL self-intersections | 0 | 0 |
| Swept clearance to duct | 2.09 mm at z = -1.14 mm, r = 49.91 mm | >= 2.0 mm |
| Rotor surface samples outside duct length | 0 | reported only |

## STL triangle quality (OpenFOAM definition)

The worst triangles are flat slivers on the hub cylinder and end caps. Splitting the hub along its axis removes them but makes OpenFOAM surfaceCheck report self-intersections at the split seams, so the hub is left whole. On design A the snapped mesh stayed within 0.018 mm of these hub surfaces (results/designA_stacked_loops_L0/CHECKS.md).

| Region | Triangles | Min quality | q < 1e-3 | q < 0.05 |
|---|---:|---:|---:|---:|
| blade | 59616 | 2.86e-03 | 0 | 469 |
| trailing edge | 2748 | 3.74e-04 | 6 | 153 |
| hub cylinder | 518 | 2.91e-06 | 39 | 188 |
| hub end caps | 164 | 1.61e-04 | 96 | 146 |

## Quantities

- Chord 12.97-19.00 mm; thickness 2.68-4.44 mm; t/c 0.160-0.300 (flare included).
- Blade volume 3566 mm3; blade wetted area 3464 mm2.
- CFD rotor volume 28573 mm3 (closed hub); printed rotor volume 21026 mm3.
- Rotor axial extent z = -15.00..15.00 mm. Duct inner radius over that span +/- 2 mm: min 52.00 mm.
- Duct: throat 104.00 mm; source STL wound inside out (flipped).

## Frames and files

Design frame: mm, rotation axis +z, omega +z, jet +z (water enters the bellmouth at -z).

| File | Frame | Use |
|---|---|---|
| `rotor_1B14.step` | design frame, mm, ring hub with spokes and spline | manufacturing / CAD |
| `rotor_1B14.stl` | metres, axis +x: (x, y, z) = 0.001 (z, y, -x) | CFD, closed hub |
| `duct_1B14.stl` | metres, axis +x | CFD |
| `rotor_1B14_sections.csv` | design frame, mm | section table |
| `preview.png` | | renders, from `scripts/render_geometry.py` |

## Sources (SHA-256)

- `prototype1B_design.json` 2e736c7b3dde47974ff4e11f274cfe7fdc914023ccfe9ac07eb8e8bd3969e738
- `CFD_DOE_27.csv` 7c785d7c39c5d1b1da7c0025307a7d9b2c9f343483e1232ffc550cee1ccddf43
- `prototype1B_duct.stl` 91eb4723b8d57da86fd672938912fa86f70fda183d30b4b12dfc233c1f2e10a7
- `prototype1B_rotor.stl` 1c829f812edae51ff8f0eb8c096b8da95af9a202298afe6baf55f15aa4a63673

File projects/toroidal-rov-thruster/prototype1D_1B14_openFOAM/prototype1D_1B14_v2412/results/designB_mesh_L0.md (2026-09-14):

# Design B (front-opening loops): L0 mesh check

Checked 2026-09-14. No flow solve has been run on design B yet. Geometry details are in [../geometry/GEOMETRY_REPORT.md](../geometry/GEOMETRY_REPORT.md), and renders in [../geometry/preview.png](../geometry/preview.png).

## Geometry checks (`Allmesh`, all mandatory, all passed)

| Check | Result |
|---|---|
| `validate_geometry.py` | Rotor radius 49.91 mm (limit 50); duct throat 104.00 mm; duct clearance 2.09 mm at x = −1.14 mm (limit 2.0) |
| MRF zone margins | r = 51 mm, x = −16.5…16.5 mm; 1.09 mm to rotor, 1.00 mm to duct (limit 0.5) |
| `surfaceCheck` rotor | Closed, 1 part, not self-intersecting, 63,046 triangles, min quality 2.9×10⁻⁶ |
| `surfaceCheck` duct | Closed, 1 part, not self-intersecting |
| `topoSet` | `mrfZone` 1,193,961 cells |

The minimum triangle quality comes from flat slivers on the hub cylinder. Splitting the hub to remove them made `surfaceCheck` fail at the split seams, so the hub stays whole; see [designA_stacked_loops_L0/CHECKS.md](designA_stacked_loops_L0/CHECKS.md), section 3. The measurements below confirm again that these slivers do not distort the mesh.

## Mesh quality (`checkMesh`: Mesh OK)

| Quantity | Design B | Design A (for comparison) |
|---|---:|---:|
| Cells | 2,010,954 | 1,893,009 |
| Hexahedra / prisms / polyhedra | 1,719,508 / 49,526 / 241,861 | 1,631,544 / 44,899 / 216,525 |
| Max non-orthogonality | 62.1 | 66.7 |
| Max skewness | 3.66 | 3.42 |
| Rotor patch faces | 189,673 | 169,661 |
| Prism layers | none | none |
| Meshing time | 14.1 min | 11.6 min |

## Does the volume mesh keep the rotor shape?

The snapped rotor patch was compared with `geometry/rotor_1B14.stl`.

**Overall:**

| Measure | Snapped mesh vs STL |
|---|---|
| Enclosed volume | 28,469 vs 28,476 mm³ (−0.02%) |
| Surface area | 13,317 vs 13,329 mm² (−0.09%) |
| Mesh point to STL distance | P50 0, P95 0, P99 0.001 mm, max 0.059 mm |

**By region:**

| Region | Mesh points | P95 distance | Max distance |
|---|---:|---:|---:|
| Trailing edge | 10,030 | 0.004 mm | 0.059 mm |
| Leading edge | 10,797 | 0.000 mm | 0.040 mm |
| Root / flare | 8,026 | 0.000 mm | 0.012 mm |
| Rest of blade | 135,343 | 0.000 mm | 0.001 mm |
| Hub cylinder | 34,548 | 0.000 mm | 0.043 mm |
| Hub end caps | 20,162 | 0.000 mm | 0.000 mm |

The worst point sits on a trailing edge near the loop apex (x = 12.9 mm, r = 43.6 mm).

**Trailing edge.** The blunt trailing edge (designed 0.4 mm) is kept. Across the TE midline the snapped mesh measures 0.54–0.63 mm at stations 20, 40, 80 and 100, and 0.85 mm at the apex (station 60). That metric reads wide where the edge curves, as it does at the apex.

**Conclusion.** The L0 mesh reproduces design B to within 0.06 mm everywhere. The 0.25 mm rotor cells capture the 0.4 mm trailing edge as a blunt edge; they neither round it off nor lose it.

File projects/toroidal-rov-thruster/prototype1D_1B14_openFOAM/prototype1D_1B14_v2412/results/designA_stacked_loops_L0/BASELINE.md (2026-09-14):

# Prototype 1B-14 L0 baseline

Steady MRF, k-omega SST, bollard (still water), seawater, 3000 rpm. Generated by `scripts/convergence_report.py`.

## Mesh and geometry

- Cells 1893009; max non-orthogonality 66.676815; max skewness 3.422999; checkMesh Mesh OK
- Rotor STL sha256 `4f4c740a5d4f183b1d134d914603ec67044e5e2d9e0b24bf64fbba3ce15b5c28`; see geometry/GEOMETRY_REPORT.md

## Result

```
Iterations: 5000; omega +314.159 rad/s; averages over the last 3000 iterations (6 batches of 500)

  Quantity                                 Mean   95% +/-    (%)  drift %  window change %  peak-to-peak %
  Thrust, total (N)                       27.03     0.452   1.67     0.86             0.23           20.96
  Thrust, rotor (N)                       18.38     0.528   2.87     1.22
  Thrust, duct (N)                        8.649     0.366   4.23     5.28
  Rotor torque (N m)                     0.4511     0.006   1.33     0.45             0.86           18.17
  Shaft power (W)                         141.7      1.88   1.33     0.45
  Thrust / power (N/W)                    0.191   0.00376   1.97     1.32
  Flow through rotor (L/s)                15.99     0.164   1.03     0.79             0.86            4.46
  Min wall pressure, rotor (kPa)         -141.3      5.58   3.95     2.75
  Min wall pressure, duct (kPa)          -59.99      1.08   1.79     1.85

  residual Ux      final 3.69e-03  dropped 2.4 decades  change over last window 0.03 decades
  residual Uy      final 5.51e-03  dropped 2.2 decades  change over last window 0.04 decades
  residual Uz      final 5.76e-03  dropped 2.2 decades  change over last window 0.03 decades
  residual k       final 2.03e-03  dropped 2.7 decades  change over last window 0.03 decades
  residual omega   final 2.88e-04  dropped 1.7 decades  change over last window 0.03 decades
  residual p       final 5.58e-04  dropped 3.2 decades  change over last window 0.14 decades
  Cavitation, rotor: mean min wall pressure -141.3 kPa gauge (worst -184.5); absolute at 1.0 m depth -29.9 kPa vs vapour 2.34 kPa; needs > 4.2 m depth
  Cavitation, duct: mean min wall pressure -60.0 kPa gauge (worst -72.3); absolute at 1.0 m depth 51.4 kPa vs vapour 2.34 kPa; clear
  y+ rotor  min 1.49  max 157.1  mean 34.7
  y+ duct   min 0.21  max 325.6  mean 48.4
  Flow direction: bellmouth intake, jet leaves through the diffuser (+x) - as designed

VERDICT: NOT CONVERGED
```

## Interpretation (added 2026-09-14)

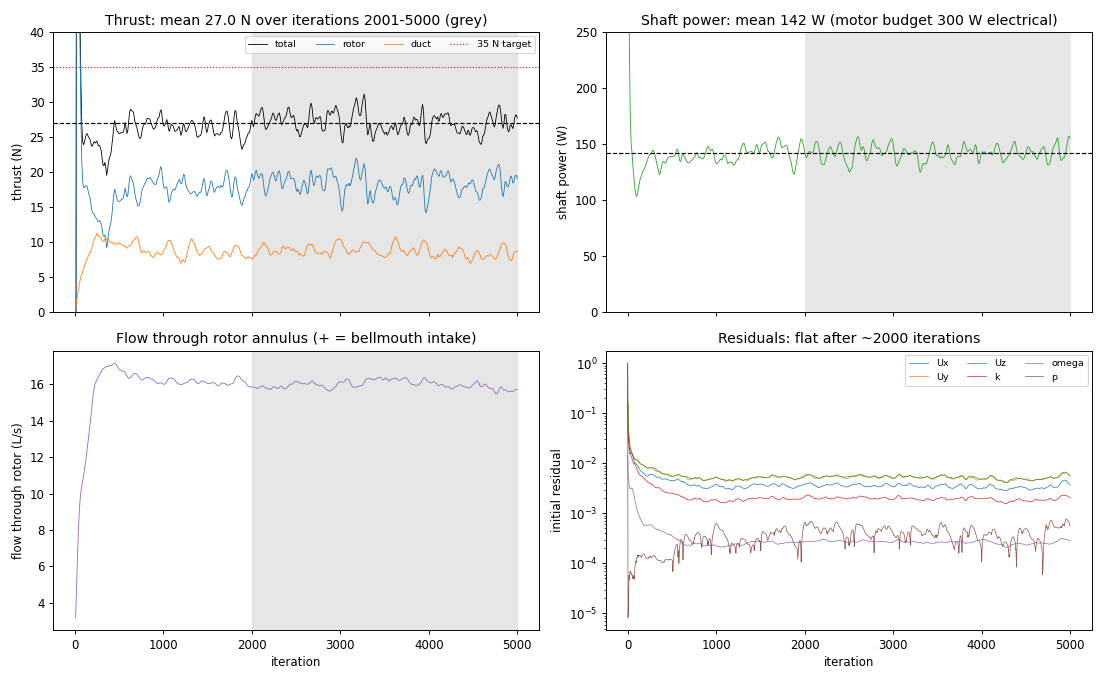
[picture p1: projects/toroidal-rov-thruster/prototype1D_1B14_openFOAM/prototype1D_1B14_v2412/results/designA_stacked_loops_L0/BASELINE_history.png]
Force, power, flow and residual histories


**Status: statistically steady in the integrated quantities, not converged.**

The steady MRF solution never settles. Thrust keeps oscillating by about ±10% about its mean, with periods of 300–1000 iterations, and the residuals have been flat at 10⁻³–10⁻⁴ since about iteration 2000.

The averages are nonetheless stable:
- thrust, torque and flow averaged over iterations 2001–5000 are each known to within ±1.0–1.7% (95%);
- averages over the last 1000, 2000 and 3000 iterations agree to within 1%.

The only statistical check that fails is the pressure residual, which is spiky and moved 0.14 decades against a 0.1 limit.

| Quantity (iterations 2001–5000) | Value |
|---|---|
| Thrust, total | 27.0 ± 0.45 N (target 35 N) |
| Thrust, rotor / duct | 18.4 ± 0.5 N / 8.6 ± 0.4 N |
| Rotor torque | 0.451 ± 0.006 N·m |
| Shaft power | 142 ± 2 W (motor budget 300 W electrical) |
| Thrust / power | 0.191 ± 0.004 N/W |
| Flow through rotor | 16.0 ± 0.2 L/s, bellmouth intake as designed |

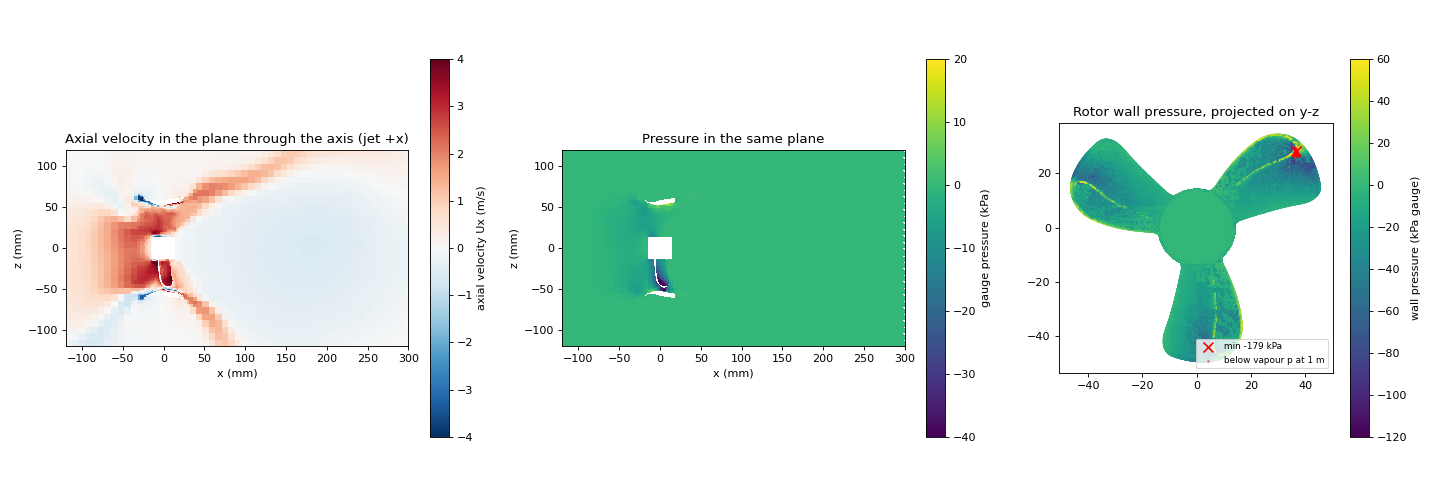
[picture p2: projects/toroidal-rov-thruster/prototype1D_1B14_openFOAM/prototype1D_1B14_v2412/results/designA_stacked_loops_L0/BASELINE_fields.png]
Velocity and pressure through the axis; rotor wall pressure


### What the fields show

- **Cavitation:** mean lowest rotor wall pressure is −141 kPa gauge. At 1 m depth, 5.3 mm² of the rotor (0.05% of its area) falls below vapour pressure, on the aft side of the loop apex (r ≈ 46 mm, stations 53–67). The patch disappears below about 4.2 m depth. At L0 with wall functions this suction peak is only indicative.
- **Jet:** water leaves the duct as a spreading hollow cone at about 40°. The flow reverses along the axis downstream, reaching −0.6 m/s at x = 200 mm. Swirl behind the rotor reaches 13 m/s.
- **Wall y+:** rotor mean 35 (max 157), duct mean 48. That is the wall-function range, as expected at L0.

### Known limitations of this baseline

1. **Wake under-resolved.** Refinement stops at x = 18 mm, and the wake behind it sits in 8 mm cells. Mean swirl drops from 2.7 m/s to 0.4 m/s between x = 20 and 40 mm, far faster than angular momentum should decay, so the hollow-cone jet and the reversed axis flow are probably partly numerical.
2. **Domain small for a bollard jet.** The box is 2D upstream, 4D downstream and 2D in radius, against the 5D / 10D / 5D in PROTOTYPE1B_DESIGN.md. About 50–56 L/s crosses the side farfield in each direction, against 16 L/s through the rotor, so the spreading jet leaves through the sides of the box.
3. **Steady MRF oscillation.** A steady rotating-frame solution cannot capture blade-passing unsteadiness. The ± values above are the uncertainty of the average, not the force ripple.
4. **Single mesh level.** No mesh-independence check yet.

Quantities at the rotor (torque, blade pressure) are less exposed to limitations 1 and 2 than the jet and wake. Treat thrust, duct thrust and T/P as provisional.

### Recommended next step

Before comparing DOE cases or judging the 35 N target:
- enlarge the domain to the design-doc size;
- add a wake refinement region (a cylinder about 60 mm in radius from x = −50 to +200 mm);
- rerun, then compare against this baseline.

Expect a mesh of about 3 M cells and a run of 6–8 hours on this laptop.

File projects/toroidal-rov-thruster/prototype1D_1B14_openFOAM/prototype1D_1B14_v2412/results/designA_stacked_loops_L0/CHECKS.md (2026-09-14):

# Design A (stacked loops), L0 baseline: sign, near-wall and surface checks

Checked 2026-09-14 on the archived L0 run (1.89 M cells, 5000 iterations). Force and moment values are means over iterations 2001–5000. Re-create the numbers with:

```bash
python3 scripts/convergence_report.py --case results/designA_stacked_loops_L0
```

## 1. Direction and force signs: confirmed

CFD frame: rotation axis +x, omega = +314.16 rad/s (right-handed about +x), jet designed toward +x.

| Quantity | Pressure | Viscous | Total |
|---|---:|---:|---:|
| Rotor Fx (N) | −18.91 | +0.53 | **−18.38** |
| Duct Fx (N) | −8.74 | +0.09 | **−8.65** |
| Assembly Fx (N) | | | **−27.03 ± 0.45** |
| Rotor Mx (N·m) | −0.368 | −0.083 | **−0.451 ± 0.006** |
| Duct Mx (N·m) | | | +0.332 |

- **Thrust direction.** Assembly Fx is negative, so the thrust on the assembly points toward −x, opposite the +x jet. It is negative in 100% of samples after iteration 500.
- **Jet direction.** Flow through the rotor annulus is +16.0 L/s, entering at the bellmouth. The wake swirls positively about +x, which matches the rotation sense.
- **Shaft power.** Shaft power = −omega·Mx = **+141.7 ± 1.9 W**. The water's moment on the rotor opposes the rotation, so the motor drives the rotor. Mx is negative in 100% of samples after iteration 500.
- **Duct torque.** The duct reacts +0.33 N·m, 74% of the rotor torque: it straightens most of the swirl.
- **Viscous share.** Viscous forces carry 18% of the rotor torque, so torque and power depend on the near-wall treatment (section 2).

`scripts/convergence_report.py` now reports the signed Fx and Mx, derives shaft power as −omega·Mx, and flags a non-positive power or a force direction that disagrees with the jet.

## 2. Near-wall treatment: no layers, y+ mostly in the buffer layer

- **No prism layers were generated.** `addLayers false`, and `log.snappyHexMesh` has no layer phase. The 44,899 prisms in `log.checkMesh` come from snapping.
- **Wall treatment.** `nutUSpaldingWallFunction` with `kqRWallFunction` and `omegaWallFunction`. These are blended functions, so any y+ is allowed, but accuracy is worst in the buffer layer.
- **Rotor surface cells.** Level 5: 0.25 mm faces, first cell centre about 0.125 mm off the wall.

Area-weighted y+ at iteration 5000. The rotor mean has stayed at 34.7–35.2 on every write from iteration 500 to 5000.

| Patch | P5 | P50 | P95 | max | y+ < 1 | 1–5 | 5–30 (buffer) | 30–100 | > 100 |
|---|---:|---:|---:|---:|---:|---:|---:|---:|---:|
| rotor | 7.6 | 24 | 77 | 157 | 0.0% | 0.8% | **60.7%** | 37.9% | 0.6% |
| duct | 1.3 | 10 | 175 | 326 | 2.3% | 34.5% | 23.2% | 24.6% | 15.4% |

- **Where y+ is highest.** Rotor: near the loop apex (x ≈ 0–2 mm, r ≈ 46–47 mm). Duct: at the throat (x ≈ 0, r = 52 mm), opposite the blade tips.
- **Implied friction velocity** on the rotor: median u_τ ≈ 0.22 m/s, P95 ≈ 0.65 m/s. Putting the first cell centre at y+ ≈ 1 needs a first layer of about 10 µm (median) or 3 µm (P95).

**Assessment.** This mesh neither resolves the viscous sublayer nor sits cleanly in the log layer, so the viscous torque carries an unquantified modelling uncertainty. Coarsening the wall cells into the log layer (y+ 30–100) would need about 0.6 mm faces, which would lose the 2.7–4.4 mm thick blades and the 0.4 mm trailing edge. The practical route is prism layers; see `results/layer_trial_L0.md`.

## 3. Poorest surface triangles: slivers on the hub, shape preserved

`log.surfaceCheck.rotor` reports a minimum triangle quality of 2.05×10⁻⁶ (OpenFOAM definition: area over the area of the equilateral triangle in the same circumcircle). The table below classifies every STL triangle by location.

| Region | Triangles | q < 1e-3 | q < 0.05 | Min q |
|---|---:|---:|---:|---:|
| hub cylinder | 679 | 40 | 147 | 2.05e-06 |
| hub end caps | 164 | 96 | 146 | 1.61e-04 |
| trailing edge | 2412 | 0 | 192 | 3.69e-03 |
| leading edge | 19087 | 3 | 3 | 1.12e-04 |
| root / flare | 2774 | 0 | 0 | 7.33e-02 |
| rest of blade | 20596 | 0 | 117 | 6.33e-03 |

- **Where the worst triangles are.** Every triangle with q < 10⁻⁵ lies on the hub cylinder, as 17 × 0.13 mm strips stretched between blade-hub intersection curves (OCC tessellation of one large cylindrical face). The end-cap fans are the next worst.
- **Blade slivers.** They follow the 0.4 mm blunt trailing-edge strip. The roots are clean.

**Does the volume mesh keep the shape?** The snapped rotor patch was compared with the STL:

| Measure | Snapped mesh vs STL |
|---|---|
| Enclosed volume | 26,770 vs 26,776 mm³ (−0.02%) |
| Surface area | 11,644 vs 11,653 mm² (−0.08%) |
| Mesh point to STL distance | P50 0, P95 0, P99 0.0005 mm, max 0.034 mm |

Distance by region:

| Region | P95 | Max |
|---|---:|---:|
| Trailing edge | 0.003 mm | 0.034 mm (near the root, r = 14.2 mm) |
| Hub cylinder | 0 | 0.018 mm |
| Hub end caps, root / flare, leading edge | ≤ 0.004 mm | |

At five stations along the loop the snapped trailing edge stays blunt, 0.50–0.58 mm across the TE midline against the designed 0.4 mm. It is neither collapsed nor rounded off.

**Conclusion.** The slivers lie flat on analytic hub surfaces and do not distort the volume mesh.

Removing them at the source was tried on design B, and rejected:

| Hub treatment | OpenFOAM self-intersection check | Min hub triangle quality |
|---|---|---|
| Unsplit (kept) | passes | 2.9×10⁻⁶ |
| Split 24 × 10 before fusing | fails, 20 locations at split seams | 1.0×10⁻² |
| Split 12 × 5 | fails, 3 locations | 6.7×10⁻⁴ |
| Split along the axis only (1 × 10) | fails, 2 locations | 8.1×10⁻⁵ |
| Split around only (24 × 1) | passes | 5.8×10⁻¹⁰ |
| Unsplit, interior mesh vertices | passes | 2.9×10⁻⁶ |
| Split after fusing | invalid solid | |

Every split along the axis makes `surfaceCheck` flag the circular split seams, and `Allmesh` treats that check as mandatory. The hub therefore stays unsplit: its slivers lie flat on the cylinder and, as measured above, do not distort the snapped mesh.

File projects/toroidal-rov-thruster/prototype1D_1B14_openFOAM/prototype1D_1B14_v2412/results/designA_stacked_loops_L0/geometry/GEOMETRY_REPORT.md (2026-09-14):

# Prototype 1B-14 rotor geometry

Generated by `scripts/make_geometry.py`. Re-running it rewrites every file in this folder.

## Why the rotor was regenerated

The recovered `prototype1B_rotor.stl` could not be repaired into a valid blade:

- the loop legs converge into a folded tip: path bend radius 0.04 mm under a 20 mm chord, legs closer than one chord beyond r = 40 mm, 1604 self-intersecting triangle pairs;
- the roots twist about 70 deg within 2 mm and the end caps sit 0.11 mm off the hub;
- all four shells were wound inside out and the envelope reached 111 mm;
- adjacent blades overlapped each other at r = 14-25 mm.

The blade below is a new SYNTHETIC design built from the same design parameters. It is not the recovered shape.

## Parameters

| Parameter | Value | Source |
|---|---:|---|
| Blades | 3 | design json |
| Hub diameter x length | 28.0 x 30.0 mm | design json |
| Root radius / apex radius (generator line) | 15.2 / 47.8 mm | design json |
| Chord root / apex | 12.5 / 19.0 mm | design json |
| Section | NACA 00xx, t/c 0.16 outboard, 0.20 at root | design json (foil_t, root_load) |
| Skew at apex | 7.0 deg, back from rotation | design json |
| Loop axial rise (apex aft of leading root) | 11.5 mm | DOE 1B-14 |
| Loading / pitch scale | 1.0 | DOE 1B-14 |
| Face pitch | 58.38 mm (P/D 0.584), constant | 2 pi r_outer tan(11.0 deg) x loading |
| Aft-leg offset | 13.0 mm normal to chord at r = 20.0 mm: +15.69 deg, +11.79 mm | this script |
| Apex turn radius | 8.81 mm | this script |
| Trailing edge thickness | 0.40 mm | repo rule 1 mm at D 250, scaled |
| Root flare over last 3.0 mm | +50% thickness, +15% chord | modelled fillet |
| closure_bias | not used | stacked legs already separate LE and TE |

## Checks

| Check | Result | Limit |
|---|---:|---|
| Envelope radius (STL) | 49.38 mm | <= 50.0 mm |
| Folded stations | 0 | 0 |
| Minimum path bend radius | 7.24 mm | > half thickness |
| Root ends inside hub | r <= 12.93 mm | <= 13.5 mm |
| Root footprint margin to hub ends | 3.75 mm | >= 0.5 mm |
| Leg-to-leg gap | 8.10 mm | >= 2 mm |
| Blade-to-blade gap | 14.27 mm | >= 2 mm |
| Blade clash volume | 0 mm3 | 0 |
| Solids after fuse | 1 | 1 |
| STL closed / consistent / parts | True / True / 1 | True / True / 1 |
| STL self-intersections | 0 | 0 |
| Swept clearance to duct | 3.36 mm at z = 3.42 mm, r = 49.27 mm | >= 2.0 mm |
| Rotor surface samples outside duct length | 0 | reported only |

## Quantities

- Chord 12.95-19.00 mm; thickness 2.68-4.44 mm; t/c 0.160-0.300 (flare included).
- Blade volume 2990 mm3; blade wetted area 2903 mm2.
- CFD rotor volume 26870 mm3 (solid hub); printed rotor volume 23476 mm3 (hub bored 12 mm for the insert).
- Rotor axial extent z = -15.00..15.00 mm. Duct inner radius over that span +/- 2 mm: min 52.00 mm.
- Duct: throat 104.00 mm; source STL wound inside out (flipped).

## Frames and files

Design frame: mm, rotation axis +z, omega +z, jet +z (water enters the bellmouth at -z).

| File | Frame | Use |
|---|---|---|
| `rotor_1B14.step` | design frame, mm, hub bored | manufacturing / CAD |
| `rotor_1B14.stl` | metres, axis +x: (x, y, z) = 0.001 (z, y, -x) | CFD, solid hub |
| `duct_1B14.stl` | metres, axis +x | CFD |
| `rotor_1B14_sections.csv` | design frame, mm | section table |

## Sources (SHA-256)

- `prototype1B_design.json` 2e736c7b3dde47974ff4e11f274cfe7fdc914023ccfe9ac07eb8e8bd3969e738
- `CFD_DOE_27.csv` 7c785d7c39c5d1b1da7c0025307a7d9b2c9f343483e1232ffc550cee1ccddf43
- `prototype1B_duct.stl` 91eb4723b8d57da86fd672938912fa86f70fda183d30b4b12dfc233c1f2e10a7
- `prototype1B_rotor.stl` 1c829f812edae51ff8f0eb8c096b8da95af9a202298afe6baf55f15aa4a63673

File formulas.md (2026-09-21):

# Formulas

The working equations, and the datum each one assumes. This repository uses these
quantities in the briefs, the tables and the CFD reports; this is where they are defined.

Where a formula is already implemented in the repository, the code is named. If the two
ever disagree, the code is what produced the numbers.

## Symbols and units

SI throughout. The geometry tables are in **mm** because that is what a CAD kernel and a
printer want; every formula below wants **metres**, so divide by 1000 first. This is the
single most common arithmetic mistake in propeller work.

| | | |
|---|---|---|
| `D` | diameter | m (tables: mm) |
| `R` | tip radius, `D/2` | m |
| `r` | radius of a blade station | m |
| `r/R` | non-dimensional radius | — |
| `c` | chord at a station | m |
| `P` | pitch — **face pitch**, see below | m |
| `Z` | number of blades | — |
| `n` | rotation rate — **revolutions per second, not rpm** | rev/s |
| `V` | speed of advance (inflow, not boat speed) | m/s |
| `T`, `Q` | thrust, shaft torque | N, N·m |
| `ρ` | density — 1025 kg/m³ seawater (the value in the CFD case), 1000 fresh, 1.225 air | kg/m³ |
| `ν` | kinematic viscosity — ≈1.05×10⁻⁶ m²/s seawater, 1.5×10⁻⁵ air | m²/s |
| `p_v` | vapour pressure of water — ≈2.3 kPa at 20 °C | Pa |

**`n` in rev/s is the trap.** Every coefficient below is defined on rev/s. Feeding it rpm
puts `Kt` out by 3600.

## Geometry ratios

The tables are published as ratios of diameter, which is exactly what lets you build the
same design at any size.

| Quantity | Formula | Notes |
|---|---|---|
| Pitch ratio | `P/D` | The number that defines how coarse a propeller is. Meaningless without its datum. |
| Non-dimensional radius | `r/R` | Blade stations run from the hub ratio out to 1.0. |
| Chord ratio | `c/D` | |
| Hub ratio | `d_hub/D` | 0.265 for this repo's ducted Kort, 0.28 for its CPP, 0.2 for DTMB 4119. |
| Expanded area ratio | `Ae/Ao = (2Z/π) ∫ (c/D) d(r/R)` | Also written BAR. Implemented as `ear()` in [cad/tools/check-geometry.py](cad/tools/check-geometry.py). |

`Ae/Ao` is an **integral**, which is why this repository's checkers do not rely on it: you
can starve the root, inflate the mid-span, and still hit the target area ratio with a blade
that is wrong. Check the distribution, not its integral.

## Pitch angle

```
β(r) = atan( P / (2πr) )
```

`β` is the angle the section is set at, and it falls off along the blade because the same
axial advance is spread over a longer circumference.

**The datum matters more than the formula.** `P` here is **face pitch** — the pitch line
through the *pressure* side of the section — which is what the Ka tables and APC's quoted
pitch use. Applying the same angle to the *chord* line instead gives a different propeller,
by degrees, on any cambered section. See [cad/CONVENTIONS.md](cad/CONVENTIONS.md).

Substituting `P = (P/D)·D` and `r = (r/R)·(D/2)`:

```
β = atan( (P/D) / (π · r/R) )
```

**`D` cancels.** At a constant `P/D`, the blade angle at a given `r/R` is the same at every
diameter — which is why a table of ratios can be built at any size, and why
`build_ducted_kort.py --diameter` only has to scale lengths.

## Operating point

| Quantity | Formula | Notes |
|---|---|---|
| Advance ratio | `J = V / (n·D)` | How far the propeller advances per turn, relative to its diameter. |
| Bollard condition | `J = 0` | Static: no inflow. The condition an ROV thruster or a tug at full pull actually works in, and the one where a duct helps most. |
| Advance angle | `atan( J / (π · r/R) )` | Compare with `β` above: the difference is roughly the angle of attack. |

DTMB 4119 in this repository is specified at its design `J = 0.833`
([dtmb4119.csv](cad/underwater/fixed-pitch/dtmb4119.csv)).

## Thrust, torque and efficiency

```
Kt = T / (ρ n² D⁴)
Kq = Q / (ρ n² D⁵)
η₀ = (J / 2π) · (Kt / Kq)
```

These three against `J` are what an **open-water curve** plots, and what the
[ITTC procedure](https://www.ittc.info/media/9621/75-02-03-021.pdf) standardises. Curves
almost always plot `10·Kq`, so that it shares an axis with `Kt` — read the axis label
before reading a value.

`η₀` is *open-water* efficiency: the propeller alone, in uniform inflow. It says nothing
about the hull in front of it.

At the bollard condition `J = 0`, so `η₀ = 0` by definition. **A static thruster has no
open-water efficiency**, and quoting one is a category error. Use thrust per watt instead:

```
T / P_shaft        where  P_shaft = 2π n Q
```

This repository's toroidal thruster reports 29.1 N at 130 W shaft, i.e. 0.225 N/W — an
unvalidated CFD number, but the right *kind* of number for a static thruster.

## Speeds

| Quantity | Formula | Notes |
|---|---|---|
| Tip speed | `π n D` | |
| Resultant speed at a station | `W = √( V² + (2π n r)² )` | At bollard, `V = 0`, so `W = 2π n r`. |
| Blade Reynolds number | `Re = c·W / ν`, taken at `r/R = 0.75` | 0.75R is the conventional reference station. |
| Tip Mach number | `π n D / a`, `a ≈ 343 m/s` in air | The aerial briefs cap this near 0.55 ([cad/aerial_cad.md](cad/aerial_cad.md)). |

Reynolds number is why **geometry scales but performance does not**. Halve the diameter at
the same rpm and you halve the tip speed and quarter the Reynolds number; the sections are
then working in a different regime, and a section that was efficient may stall.

## Cavitation

```
σ = (p₀ − p_v) / (½ ρ V²)
```

`p₀` is the local absolute pressure — atmospheric plus `ρgh` at depth `h`. For propellers
the reference speed is often taken as `nD` rather than `V`, giving `σ_n = (p₀ − p_v)/(½ρn²D²)`;
state which one you mean.

Cavitation begins where the **local** pressure on the blade falls to `p_v`. In a CFD result
reported as gauge pressure, that threshold is roughly `p_v − p_atm ≈ −99 kPa` at the
surface, and it moves down by about 10 kPa per metre of depth. So a minimum wall pressure
of −180 kPa gauge implies vapour unless you are deeper than about 8 m — which is exactly
how the toroidal thruster's cavitation margin was read.

Thin, uncambered sections at high angle of attack produce the sharpest suction peaks. That
is a geometry decision, not an operating one.

## Rules of thumb worth knowing

- **Bigger and slower beats smaller and faster.** For a given thrust, efficiency rises with
  diameter. Gear down before you speed up.
- **Thrust goes roughly as `n²`, power as `n³`.** Ten percent more rpm is about 21% more
  thrust and 33% more power.
- **Tip clearance is a fraction of diameter, not a fixed gap.** 1.5 mm is 0.6% of a 250 mm
  propeller and 1.5% of a 100 mm one. In a duct, that gap is a leak.
- **A duct pays at low `J` and costs at high `J`.** Tugs, trawlers and ROV thrusters gain;
  a fast open boat loses.

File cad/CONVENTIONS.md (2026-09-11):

# Geometry Conventions

Definitions the build briefs leave implicit. **Only what is missing** — frame, units, section seam,
point count, winding, cylindrical placement, fillets-last and handedness are already defined in
[underwater_cad.md](underwater_cad.md) § Conventions and § Modelling notes, and are not restated here.

Every geometry CSV carries these as a declaration block in its header, so a script author reading one
table never has to come back here to interpret it.

## Pitch datum — FACE pitch

`P` is the **face pitch**: the pitch of the pitch line through the **pressure side** of the section.
`β(r) = atan(P / (2πr))` rotates the section about that line, not about its chord line.

Not a preference — it is what the repo's real data already uses:

- The Ka-series offsets in [underwater/ducted-kort/ka-sections.csv](underwater/ducted-kort/ka-sections.csv)
  are stated by their source as "referenced to the pitch line through the **pressure side** of the blade".
- APC's `pitch_quoted_in` in [aerial/fixed-pitch/apc-10x5e.csv](aerial/fixed-pitch/apc-10x5e.csv) is
  defined "with a flat bottom surface" — face pitch for a flat-bottomed section such as Clark-Y.

APC publish three pitch columns per station because the definitions genuinely disagree. Use
`pitch_quoted_in`. Using `pitch_le_te_in` instead changes blade angle by degrees, which is a different
propeller.

## Generator line — mid-chord marine, leading edge aerial

The generator line is the radial line the sections are placed and rotated about. It differs by domain
because the source data differs, so **every file declares its own**:

| Domain | Generator line | Why |
|---|---|---|
| Marine | 50% chord (mid-chord) | standard marine blade-reference-line practice |
| Aerial | leading edge | APC define sweep and rake "with (mold) LE parting line" |

Move the generator line and the whole blade moves. It is not a detail.

## Rake — generator-line rake only

`rake_z_D` is **generator-line rake**: the axial offset of the generator line itself. It does **not**
include skew-induced rake.

Total rake = generator rake + skew-induced rake, where the skew-induced part is what the section
picks up axially by being displaced along the pitch helix. A build script must add it when placing
sections. On a highly skewed blade the two are comparable in size — at DTMB 4384's 108° tip skew,
treating `rake_z_D` as total rake misplaces the tip axially by more than the rake itself.

## Skew — circumferential angle of the generator point

`skew_deg` is the angular displacement of the section's generator point from the straight radial
reference, positive opposite to the direction of rotation (blades sweep back). Measured in the disc
plane as an angle, not as an arc length along the pitch helix.

## Camber — `f_c` is maximum camber over local chord

`f_c` = maximum camber / local chord, of the mean line. Combined with `t_c` (or `t_D`) it completes
the section: **pitch sets the angle the section meets the flow, camber sets the lift it makes at that
angle.** A table with chord, thickness and pitch but no camber does not define a section.

Wedge designs — `supercavitating` and `surface-piercing` — carry **no** `f_c` on purpose. A
supercavitating wedge has a flat pressure face and a straight suction ramp; it has no mean-line
camber, and adding one would make it a different section family.

## Root fillet — `fillet_r_D`

Fillet radius over the blade-to-hub blend, as a fraction of `D`, zero outboard of the blend region.
It sits in the planform tables beside `t_D` so the brief's rule — *"keep the radius below the local
thickness"* — is checkable in one line rather than across two files.

`cad/underwater_cad.md` § Modelling notes says OCCT fillets fail on lofted blade roots more often than
they succeed, and to model the blend as extra loft sections instead. This column is that schedule.

## Hub

`hub.csv` per design: truncated cone, keyed taper bore. `rim-driven` has **none** and must not acquire
one — it is hubless by definition, with the blades cantilevered inward from the motor ring. `pump-jet`
(ogive nose and tail cone), `voith-schneider` (rotor casing) and `podded-azimuth` (pod body) use other
forms and likewise take no taper-bore hub.

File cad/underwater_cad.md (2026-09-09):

# Underwater CAD Prompts

Build briefs for every design in [underwater_designs.md](../underwater_designs.md). Each section is
self-contained: hand one to a CAD agent and it should produce a model without further context.
Six designs are built and live under [`underwater/`](underwater/); each of those sections carries a
**Built** note recording what the mesh measures against its **Done when**. Every other section is
still a prompt only. Status at a glance, and the findings common to all six: [README.md](README.md).

## Conventions

- **Tooling** — script-first: CadQuery (Python) or FreeCAD's Python API. The script is the
  deliverable, not a GUI session.
- **Parameters** — open every script with a parameter block. Changing a value and re-running must
  give a valid model; nothing dimensional is hard-coded downstream.
- **Frame** — hub front face at `Z = 0`, thrust toward +Z, angular velocity along +Z by the
  right-hand rule, so a blade sweeps from +X toward +Y. Rotation sense and pitch sign together decide
  which way the propeller pushes, so they are not independent settings: with ω along +Z the pressure
  face has to end up looking toward −Z. Verify that on the built model instead of assuming it.
- **Units** — millimetres and degrees. Defaults below are ROV/AUV scale so the models stay
  printable; every design is scale-free, so a ship-scale diameter must work by changing one number.
- **Output** — `cad/underwater/<slug>/` holding `model.step`, `model.stl` and the script.
- **Shared checks** — the solid is watertight and manifold, blade count matches, nothing
  self-intersects, blades clear each other through their full travel, both STEP and STL export.
- **Wet-specific** — no knife-edge trailing edges: hold a minimum TE thickness (1 mm at this scale)
  so the blade is castable and printable. Blade root fillets are large; a cavitation-prone sharp
  corner is a modelling defect, not a detail.

## Modelling notes

Craft rules that decide whether these models build at all. Cheap to follow, tedious to retrofit.

- **Section wires** — every section in a loft needs the same point count, the same seam (start at the
  trailing edge) and the same winding direction. Get this wrong and the loft quietly twists between
  stations rather than failing. Marine blades make this worse than aerial ones: heavy skew already
  shifts each section circumferentially, so a drifting seam is easy to mistake for skew.
- **Cylindrical placement** — there is no "wrap onto a cylinder" operation, so do not go looking for
  one. Build the section in 2D, then map each point onto the cylinder of radius `r` before making the
  wire: circumferential distance `x` becomes the angle `x/r`. Marine sections are defined on
  cylindrical surfaces by convention, so unlike small air propellers, the flat-section shortcut is
  not available here.
- **Fillets last** — fillet after the blades are unioned to the hub, never before, and keep the
  radius below the local thickness. OCCT fillets fail on lofted blade roots more often than they
  succeed; when one does, model the blend as extra loft sections instead of fighting the operation.
  Marine root fillets are large enough that modelling them into the loft is usually the better path.
- **Handedness** — to build the opposite-hand version, mirror in a plane that *contains* the shaft
  axis (XZ), not in the disc plane. Both flip handedness, but the XZ mirror leaves the hub taper and
  keyway pointing the way they started.
- **Motion and clash checks** — script CAD has no kinematics. Where a brief asks for something to
  sweep or articulate — CPP pitch travel, a pod slewing — sample the range at fixed poses,
  boolean-intersect the parts at each pose, and assert the intersection volume is zero. That is the
  check; a rendered animation is not.
- **Export** — STEP (AP242) is the source of truth. Write the STL from the same solid at a stated
  tessellation tolerance (0.05 mm linear deflection is a reasonable default): a blade exported at the
  default deflection looks faceted and measures wrong.
- **Validity** — assert the solid is valid before export, then read the STL back and confirm
  `is_watertight` and consistent winding with [trimesh](https://trimesh.org/). Report the volume too
  — a blade whose loft self-intersects will usually still export, and the volume is what gives it
  away. On a marine blade also report expanded area, since that is the number the series parameters
  claim and the easiest one to get silently wrong.

## Blade loft recipe

Most designs below are a lofted blade. Build it the same way each time and note only the deviations.
This is the aerial pipeline plus the two things marine blades always carry — skew and rake.

1. Pick station radii `r/R` from the hub (0.2) to the tip (1.0), spaced closer outboard.
2. At each station set chord `c(r)`, thickness `t(r)`, pitch angle `β(r) = atan(P / (2πr))`, plus
   **skew** `θs(r)` (circumferential offset of the section, zero at the root) and **rake** `i(r)`
   (axial offset, usually linear at a fixed rake angle).
3. Map each section onto the cylinder of radius `r` (see Modelling notes — a coordinate transform,
   not a wrap operation), displaced by its skew and rake. Marine sections are cambered aerofoils with
   a flat-ish pressure face.
4. Loft through the sections, cap the tip.
5. Circular-pattern by blade count about +Z, union with the hub, fillet the root generously.

The hub is a truncated cone with a keyed taper bore unless a design says otherwise.
[PropCad](https://www.hydrocompinc.com/solutions/propcad/) is the commercial version of exactly this
pipeline — its parameter list (chord, thickness, skew, rake, section offsets) is a good checklist.

## Fixed-pitch (FPP)

**Model** — one-piece cast-style propeller on standard series geometry; the baseline the other
underwater designs are judged against.

**Parameters** — `D = 250`, `Z = 4`, `P/D = 1.0`, expanded area ratio (`Ae/Ao`) 0.55, hub ratio
`d/D = 0.167`, rake 15°, Wageningen B section offsets.

**Build** — the loft recipe unchanged, with `c(r)`, `t(r)` and the section offsets taken from the
B-series tables rather than invented.

**Done when** — geometry cross-checks against the
[B-series generator](https://www.wageningen-b-series-propeller.com/) at the same inputs (diameter,
`Z`, `P/D`, area ratio) within a few percent on blade area and pitch at `r/R = 0.7`.

## Controllable-pitch (CPP)

**Model** — hub that rotates its blades in service, with detachable blades: hub body, blade palms,
crosshead and crank internals.

**Parameters** — hub ratio 0.28 (much fatter than an FPP hub, it has to contain the mechanism),
`Z = 4`, circular blade palm Ø `0.30 D` on a 4-bolt circle, crank pin offset from the palm axis,
pitch range +35° ahead to −20° astern.

**Build** — blade from the loft recipe but terminating in a cylindrical palm instead of blending
into the hub. Hub body gets a palm bore per blade with an O-ring groove; inside, a piston drives a
crosshead whose sliding blocks turn each crank pin. Pitch angle is the driven parameter.

**Done when** — blades clear one another across the whole pitch range including full astern (this,
not thrust, is what caps blade area on a CPP), and the palm bolt circle repeats identically on every
blade.

## Tip-loaded (Kappel / CLT)

**Model** — the FPP blade with its tip turned into an end plate, in both variants from one script.

**Parameters** — base FPP, plus a variant flag: **Kappel** rakes the tip smoothly toward the suction
side, **CLT** turns it into a discrete end plate on the pressure side. Transition starts at
`r/R = 0.85`; tip rake height and end-plate height as fractions of `R`.

**Build** — for Kappel, drive the existing rake term with a nonlinear tip curve so the blade sweeps
into the rake with continuous curvature — it is a bent blade, not a blade with a plate on it. For
CLT, build an actual end plate standing off the pressure side with a defined root fillet.

**Done when** — both variants come out of the same script by flag, the Kappel tip is curvature-
continuous with no crease at the transition, the CLT plate stands on the pressure side (getting the
side backwards silently turns one design into the other), and tip rake height is reported as a
fraction of `R`.

## Ducted propeller / Kort nozzle

**Model** — propeller inside a fixed accelerating nozzle, as a two-part assembly.

**Parameters** — nozzle inner Ø 250, 19A profile ordinates, length/diameter 0.5, propeller plane at
mid-nozzle, tip clearance 1.5 (~0.6% of Ø); propeller is Ka-series, `Z = 4`, area ratio 0.70,
`P/D = 1.0`, with a wide tip chord and a square cut-off tip.

**Build** — revolve the 19A ordinates about +Z for the nozzle, keeping the inner wall cylindrical
across the propeller plane. Propeller by the loft recipe, but do not round the tip — the Ka blade
ends square, close to the nozzle wall.

**Done when** — tip clearance is uniform to within 0.1 all round, the nozzle inner wall is truly
cylindrical over the blade sweep, and the blade tip is square rather than faired.

**Built** — [`underwater/ducted-kort/model.stl`](underwater/ducted-kort/model.stl), the strongest
of the six. Two solids: nozzle (genus 1) and propeller (genus 0). Nozzle inner Ø 250.0, length 125 =
0.5 D, propeller Ø 247.0 at `Z = 4` centred on the nozzle mid-plane, so the tightest tip clearance is
exactly 1.50. Open: sampled inner-wall radius runs 125.0 to 126.0 across the blade's axial span, so
the 0.1 mm uniformity is not demonstrated — check the wall against the 19A ordinates. The hub is a
plain Ø 65.4 cylinder with flat caps: no bore, no taper, no keyway.

### Pump-jet

**Model** — rotor and stator fully enclosed in a long shroud, with a faired hub — the quiet
submarine/torpedo variant of the ducted propeller.

**Parameters** — shroud length `1.0 D`, rotor `Z = 7`, stator `V = 15`, tip gap 0.5 (~0.2% of Ø), hub
an ogive nose and a tapered tail cone.

Two choices decide this design, and the application sets both. **Stator side:** a submarine puts the
stator *upstream* (pre-swirl), where it straightens the hull and appendage wake before the rotor
meets it — that is the quiet arrangement, and it is the point of the whole propulsor. A torpedo puts
it *downstream* (post-swirl), where it recovers rotor swirl and contributes on the order of a quarter
of total thrust. State which vehicle the model is for and place the stator accordingly.
**Vane count:** not "coprime" — Tyler–Sofrin again, `V ≥ 2Z` to cut off the fundamental, hence 15
against a 7-blade rotor.

**Build** — shroud as a revolved annular section with a thick inner wall (decelerating flow, which
is the point: it suppresses cavitation). Rotor by the loft recipe with high skew and high solidity.
Stator vanes are constant-section struts, joined shroud to hub, and they carry the hub.

**Done when** — `V ≥ 2Z` holds, the stator is on the side the stated application calls for, the flow
path is continuous with no step at the rotor plane, and the hub is supported only by the stator vanes.

**Built** — [`underwater/pump-jet/model.stl`](underwater/pump-jet/model.stl), with three failures
that each require a rebuild rather than a fix.

1. **The rotor cuts through the shroud.** Rotor tip radius is 134.54 against a shroud inner radius of
   125.00 — the blades pass through the duct wall by 9.5 mm. The 0.5 tip gap wants a 124.5 tip.
2. **The stator is inside the rotor, not upstream or downstream of it.** Vanes span −15 to +15 on the
   axis, wholly within the rotor's −42 to +42, and the two overlap radially from 45 to 127, so they
   interpenetrate. The submarine-versus-torpedo choice this brief calls the point of the design has
   not been made, and the geometry cannot express it until the stator moves off the rotor plane.
3. **The axis is Y, not Z**, against the frame convention every other model in this set follows.

Passing: `V = 15 ≥ 2Z = 14`, so Tyler–Sofrin cut-off holds; shroud inner Ø 250 and length 250 = 1.0 D.
Also worth fixing on the rebuild: the 15 vanes are 12-triangle rectangular boxes rather than sections,
and hub, shroud and vanes are three separate solids, so "the hub is supported only by the stator
vanes" is asserted by position rather than expressed as geometry.

## Rim-driven (hubless)

**Model** — blades carried on a motor-rotor ring inside a duct, with no hub and no shaft anywhere in
the model.

**Parameters** — duct inner Ø 250, `Z = 5`, ring axial length, magnetic gap between ring OD and duct
stator ID 1.5, open centre (true hubless) or a small nose fairing as a flag.

**Build** — the structure is inverted relative to every other propeller here: each blade is
cantilevered *inward* from the ring, so its structural root is at the tip radius and its free end is
at the smallest radius. Loft the blade the usual way, then fix the outer end into the ring and leave
the inner end free. The ring is a plain annulus with a magnet-pocket band.

**Done when** — there is no shaft, no hub bore and no centre boss; blades meet the ring with a fillet
and are unsupported at the inner radius; and the ring-to-stator gap is uniform all round, since that
gap is both the motor airgap and a viscous drag path.

**Built** — [`underwater/rim-driven/model.stl`](underwater/rim-driven/model.stl). The rotor is
right, and it is right in the way that matters: genuinely hubless, with no shaft, no bore and no
centre boss anywhere in the file. Five blades cantilever inward from the ring and end free at
r = 38.2 (0.31 R), unioned with the ring as a single solid. Duct inner Ø 250 against a ring OD of
247 gives the 1.5 magnetic gap, uniform all round. Open: the duct is a plain rectangular annulus —
radii 125 and 143, nothing else — with no stator band and no hydrodynamic section, and the 16 magnets
are separate blocks overlapping the ring rather than sitting in the magnet-pocket band the brief asks
for.

## Contra-rotating (CRP)

**Model** — two propellers on coaxial shafts turning opposite ways, plus the shaft stub that shows
how they nest.

**Parameters** — forward `D = 250` with `Z = 4`, aft `D = 0.90 ×` forward with `Z = 5` (coprime with
the forward count), axial gap `0.25 D`, opposite handedness, inner shaft driving the aft propeller
through an outer sleeve driving the forward one.

**Build** — forward propeller by the loft recipe; the aft one is the same script mirrored in the XZ
plane (see Modelling notes) with its own diameter and blade count. Model the shaft and sleeve as
plain concentric stubs; annotate the bearing and seal space rather than detailing it.

**Done when** — handedness is a genuine mirror rather than a rotation, blade counts share no common
factor, and the aft propeller stays inside the forward propeller's slipstream diameter at the
modelled gap.

**Built** — [`underwater/contra-rotating/model.stl`](underwater/contra-rotating/model.stl). The
intended pair is correct and there is a third propeller in the file that should not be there.

Correct: forward propeller Ø 249.8 at `Z = 4` running on the sleeve (Ø 31 bore on a Ø 30 sleeve); aft
propeller Ø 224.8 = 0.90 D at `Z = 5` running on the shaft; mid-plane separation 62.5 = 0.25 D; blade
counts coprime; and the aft propeller is a genuine mirror, not a rotation — its per-blade pitch slopes
are the exact negation of the third body's.

Wrong: that third body, a second `Z = 5` propeller sitting at z = 0, is the un-mirrored original left
behind. It carries the same hand as the forward propeller, and its Ø 15 bore clashes hard with the
Ø 30 sleeve that runs straight through it. Delete it; nothing else in this model needs to change.

## Surface-piercing (SPP)

**Model** — cleaver-bladed propeller built to run half out of the water.

**Parameters** — `D = 250`, `Z = 5`, `P/D = 1.4`, area ratio 0.75, trailing-edge thickness 3% of
chord, 2° of cup at the trailing edge, small hub with a taper bore, aft rake 12°.

**Build** — the loft recipe with wedge sections instead of aerofoils: flat pressure face, straight
ramp back, sharp leading edge, deliberately blunt thick trailing edge. Blade outline is a cleaver —
swept leading edge, near-radial trailing edge, tip cut square. Add the cup as a curl of the trailing
edge over the outer third of the blade.

**Done when** — every section is a wedge, not an aerofoil (check the maximum thickness sits at the
trailing edge, not mid-chord), TE thickness meets the parameter at all stations, and the tip is
square.

**Built** — [`underwater/surface-piercing/model.stl`](underwater/surface-piercing/model.stl), and
alone in this set it is a single watertight solid unioned with its own hub (genus 1, Ø 16.5 bore) —
the thing every other design here failed to be. `Z = 5` is right. Ø 285.6 against the 250 parameter.
The tip is tapered, chord about 9 mm and still falling at the last station, where the brief wants a
cleaver outline with the tip cut square, so the planform is not yet an SPP planform. Whether the
sections are wedges, whether TE thickness holds 3% of chord, and whether the cup exists over the outer
third cannot be read from a mesh this sparsely sectioned.

## Supercavitating

**Model** — fully submerged propeller whose blades are shaped to run inside their own vapour cavity.

**Parameters** — `D = 250`, `Z = 3`, `P/D = 1.6`, expanded area ratio 0.55, sharp leading edge with a
stated included angle, trailing-edge thickness 4% of chord, design speed recorded in the parameter
block.

**Build** — wedge sections as in the SPP, but the physics differ and the model should not be a copy:
here the blade stays submerged and the cavity springs from a sharp leading edge and closes *behind*
the blade, rather than being fed with atmospheric air through the free surface. Sharp leading edge,
straight ramp on the suction side, square base at the trailing edge.

**Done when** — maximum thickness sits at the trailing edge, the leading-edge included angle meets
spec at every station, and the design speed is recorded in the output — the geometry is poor below
it, so a model without that number is not usable.

**Built** — [`underwater/supercavitating/model.stl`](underwater/supercavitating/model.stl), and the
blades are not attached to anything. The file holds four disjoint solids: a hub topping out at
z = +35, and three blades whose lowest point is z = +39.62. That is a 4.62 mm air gap with nothing
unioned across it — the propeller does not exist as a body, and the three blades would print as loose
parts. `Z = 3` is right; Ø 297.7 against the 250 parameter. The hub is a plain Ø 70 × 70 cylinder with
a straight Ø 24 bore where the brief's default is a truncated cone with a keyed taper bore. And the
design speed is recorded nowhere — the brief is explicit that the geometry is poor below it, so a
model without that number is not usable even once the blades are joined on.

## Skewed blade

**Model** — the FPP again with skew promoted from a fixed number to the design variable, plus a
comparison sweep.

**Parameters** — same as FPP, but `θs(r)` is a spline: zero at the root, maximum at the tip, with tip
skew as the single input. Build at 0°, 15°, 30° and 45° tip skew; anything above 25° is a "highly
skewed" blade.

**Build** — the loft recipe with the skew term driven by the spline. Use balanced skew — the skew
line crosses the generator line, so the blade's centre of pressure stays near the pitch axis and the
spindle torque stays low. Emit one model per skew value into the same folder.

**Done when** — the four models differ only in skew, each is watertight, and the report notes for
each: blade tip circumferential offset, and whether the tip has moved far enough aft that the blade
would need thickening (the real cost of skew, and why 45° is not free).

## Loop / toroidal (Sharrow)

**Model** — marine closed-loop blade: each blade leaves the hub, loops, and returns, with no free tip.

**Parameters** — `D = 250`, 3 loops, chord scheduled along the loop path, maximum loop width, the two
root joint positions per loop, and a minimum section thickness that holds all the way round.

**Build** — a sweep along a closed 3D path, as in the aerial toroidal brief, but with marine sections
throughout: thicker, blunt trailing edge, and a leading-edge radius chosen with cavitation in mind
rather than a knife edge. Hub is the standard truncated cone with a taper bore.

**Done when** — the loop is tangent-continuous, nothing self-intersects where the return branch
passes the leading branch, minimum thickness holds around the whole loop including the return, and
both roots blend into the hub with a fillet.

## Voith Schneider (cycloidal)

**Model** — rotor casing with vertical blades on an orbit and the linkage that sets their pitch.

**Parameters** — orbit Ø 300, `N = 5` blades, blade span 240 (0.8 × orbit Ø), chord 70, symmetric
hydrofoil section at 16% thickness, pitch axis at 30% chord, eccentricity `e` (0 to 1 of orbit
radius) and its direction as the control input.

**Build** — blades hang below a rotating disc set flush in the hull plate, each on a vertical pitch
shaft. The kinematics are the whole design: pitch is set so every blade's chord stays perpendicular
to the line from that blade's axis to a movable steering centre `N`. With `N` on the rotor axis the
blades feather and net thrust is zero; offsetting `N` produces thrust perpendicular to the offset,
growing with `|e|`. Model the linkage that enforces this, not just the blades.

**Done when** — `e = 0` gives zero net thrust with every blade tangent to its orbit, sweeping the
direction of `e` rotates the thrust vector a matching amount, and the pitch-versus-azimuth table
exports for one full revolution.

## Podded azimuth thruster

**Model** — steerable pod assembly: strut, pod housing sized around a motor, propeller, and the slew
interface it turns on.

**Parameters** — propeller `D = 250` (the FPP brief, unchanged), pod body Ø `0.5 D`, pod length
`2.5 D`, strut chord and thickness, slew ring Ø, and a flag for tractor (propeller forward) or pusher.

**Build** — pod is a body of revolution with a faired nose and tail cone; the strut is a symmetric
section joining pod to hull plate; the propeller mounts on the pod nose for a tractor unit and the
tail for a pusher. Model the slew ring as a real annular joint with a declared rotation axis, so
steering is a driven parameter and not a fixed pose.

**Done when** — the assembly sweeps a full 360° about the slew axis with no clash against the hull
plate at any angle, the propeller clears the strut leading edge by the stated margin, and
tractor/pusher is a flag rather than a second script.

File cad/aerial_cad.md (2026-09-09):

# Aerial CAD Prompts

Build briefs for every design in [aerial_designs.md](../aerial_designs.md). Each section is
self-contained: hand one to a CAD agent and it should produce a model without further context.
Nothing here has been built yet — these are the prompts.

## Conventions

- **Tooling** — script-first: CadQuery (Python) or FreeCAD's Python API. OpenSCAD is fine where a
  part is pure primitives, as [bladegen](https://github.com/tallakt/bladegen) already does. The
  script is the deliverable, not a GUI session.
- **Parameters** — open every script with a parameter block. Changing a value and re-running must
  give a valid model; nothing dimensional is hard-coded downstream.
- **Frame** — hub front face at `Z = 0`, thrust toward +Z, angular velocity along +Z by the
  right-hand rule, so a blade sweeps from +X toward +Y. Rotation sense and twist sign together decide
  which way the propeller pushes, so they are not independent settings: with ω along +Z the pressure
  face has to end up looking toward −Z. Verify that on the built model instead of assuming it.
- **Units** — millimetres and degrees.
- **Output** — `cad/aerial/<slug>/` holding `model.step`, `model.stl` and the script.
- **Shared checks** — the solid is watertight and manifold, blade count matches, nothing
  self-intersects, blades clear each other through their full travel, both STEP and STL export. See
  Modelling notes for how to actually check each of these.

## Modelling notes

Craft rules that decide whether these models build at all. Cheap to follow, tedious to retrofit.

- **Section wires** — every section in a loft needs the same point count, the same seam (start at the
  trailing edge) and the same winding direction. Get this wrong and the loft quietly twists between
  stations rather than failing.
- **Cylindrical placement** — there is no "wrap onto a cylinder" operation, so do not go looking for
  one. Build the section in 2D, then map each point onto the cylinder of radius `r` before making the
  wire: circumferential distance `x` becomes the angle `x/r`. On small propellers a flat section
  placed tangentially is a fair simplification — if you take it, say so in the script.
- **Fillets last** — fillet after the blades are unioned to the hub, never before, and keep the
  radius below the local thickness. OCCT fillets fail on lofted blade roots more often than they
  succeed; when one does, model the blend as extra loft sections instead of fighting the operation.
- **Handedness** — to build the opposite-hand version, mirror in a plane that *contains* the rotation
  axis (XZ), not in the disc plane. Both flip handedness, but the XZ mirror leaves the hub and its
  mounting face pointing the way they started.
- **Motion and clash checks** — script CAD has no kinematics. Where a brief asks for something to
  sweep, fold or articulate, sample the range at fixed poses, boolean-intersect the parts at each
  pose, and assert the intersection volume is zero. That is the check; a rendered animation is not.
- **Export** — STEP (AP242) is the source of truth. Write the STL from the same solid at a stated
  tessellation tolerance (0.05 mm linear deflection is a reasonable default): a blade exported at the
  default deflection looks faceted and measures wrong.
- **Validity** — assert the solid is valid before export, then read the STL back and confirm
  `is_watertight` and consistent winding with [trimesh](https://trimesh.org/). Report the volume too
  — a blade whose loft self-intersects will usually still export, and the volume is what gives it
  away.

## Blade loft recipe

Most designs below are a lofted blade. Build it the same way each time and note only the deviations.

1. Pick station radii `r/R` from the hub joint (~0.15) to the tip (1.0), spaced closer outboard.
2. At each station set chord `c(r)`, thickness ratio `t/c`, and twist `β(r) = atan(P / (2πr))` for a
   constant-pitch blade — quoted pitch is the value at `r/R = 0.75`.
3. Scale the section airfoil to `c`, rotate it by `β`, and map it onto the cylinder of radius `r`
   (see Modelling notes — this is a coordinate transform, not a wrap operation).
4. Loft through the sections and cap the tip.
5. Circular-pattern by blade count about +Z, union with the hub, fillet the root joint (1–2 mm).

Take real chord and twist distributions from the
[UIUC database](https://m-selig.ae.illinois.edu/props/propDB.html) rather than inventing a planform;
APC publish blade offsets directly as
[`.peo` files](https://www.apcprop.com/technical-information/file-downloads/).

## Fixed-pitch (low-Re)

**Model** — one-piece two-blade propeller; the baseline the other aerial designs are judged against.

**Parameters** — `D = 254` (10 in), `P = 127` (5 in), `Z = 2`, hub Ø 12, bore Ø 5, root at
`r/R = 0.15`, Clark-Y or Eppler E63 sections, `t/c` 14% at the root tapering to 9% at the tip, chord
peaking near `r/R = 0.6`.

**Build** — the loft recipe unchanged, with `c(r)` and `β(r)` lifted from a UIUC entry of the same
nominal size.

**Done when** — pitch measured back off the model at `r/R = 0.75` is within 2% of `P`, and the bore
is concentric with the rotation axis.
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

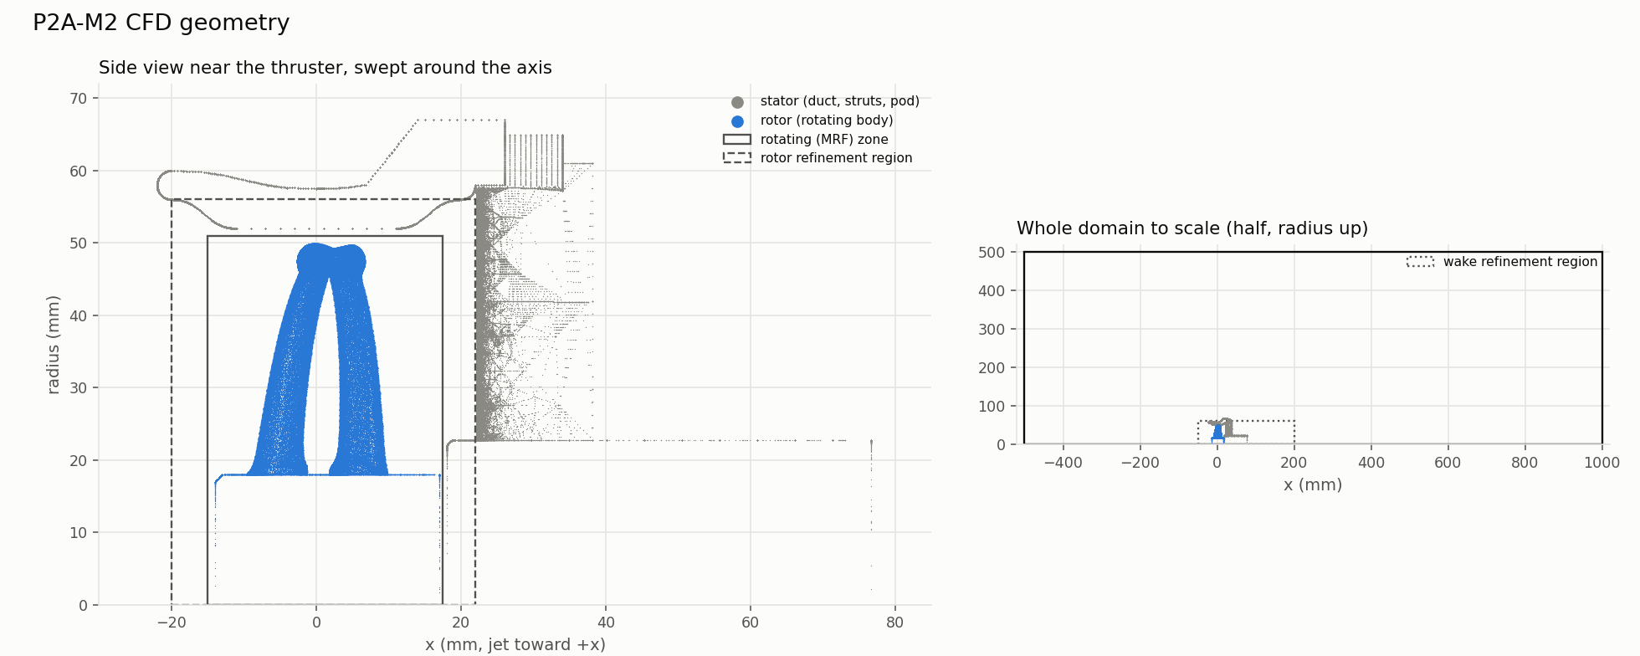
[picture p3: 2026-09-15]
projects/toroidal-rov-thruster/prototype2A_M2_openFOAM/geometry/preview.png

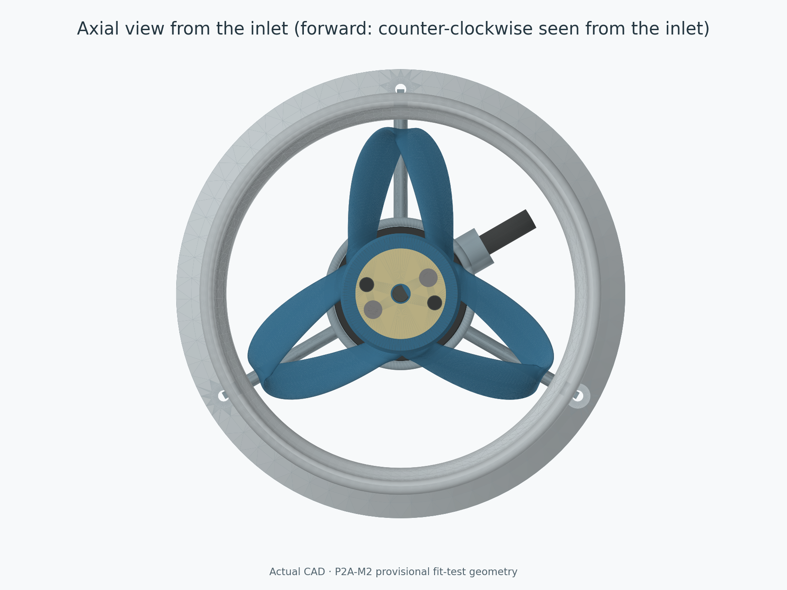
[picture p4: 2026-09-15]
projects/toroidal-rov-thruster/toroidal_rov_prototype2A/thruster_proto2A/previews/axial.png

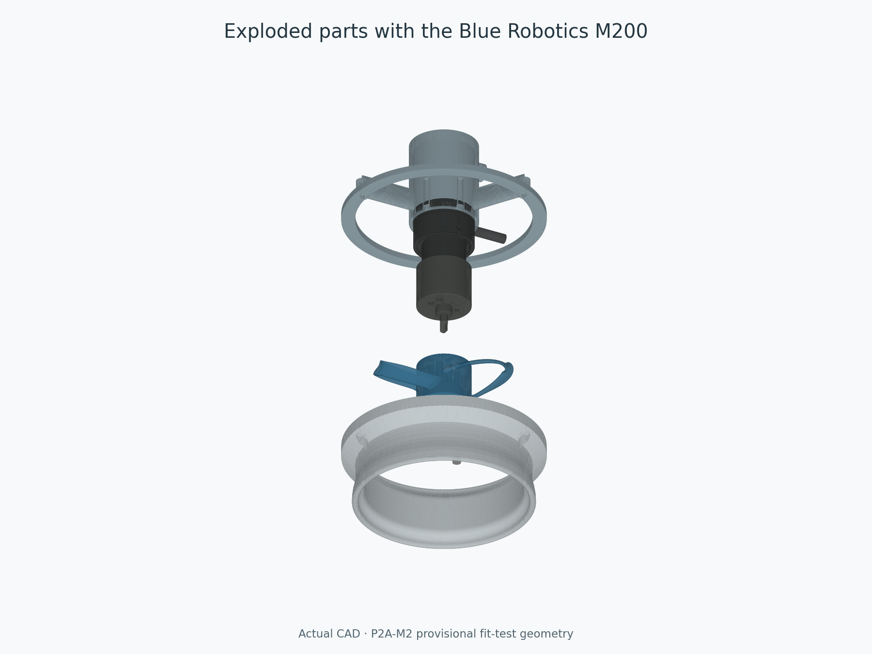
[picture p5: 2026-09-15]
projects/toroidal-rov-thruster/toroidal_rov_prototype2A/thruster_proto2A/previews/exploded.png

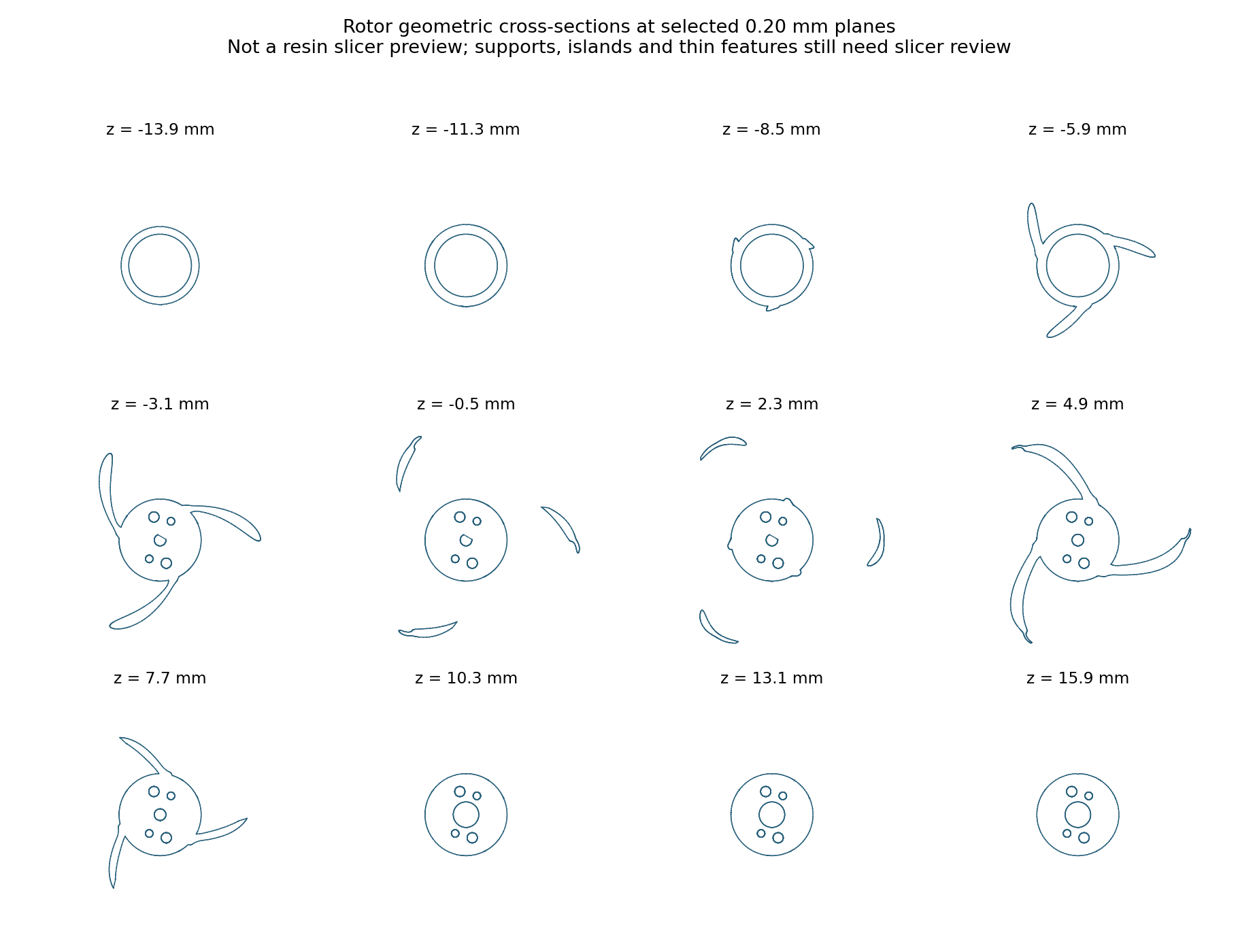
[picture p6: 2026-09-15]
projects/toroidal-rov-thruster/toroidal_rov_prototype2A/thruster_proto2A/previews/rotor_layer_sections.png

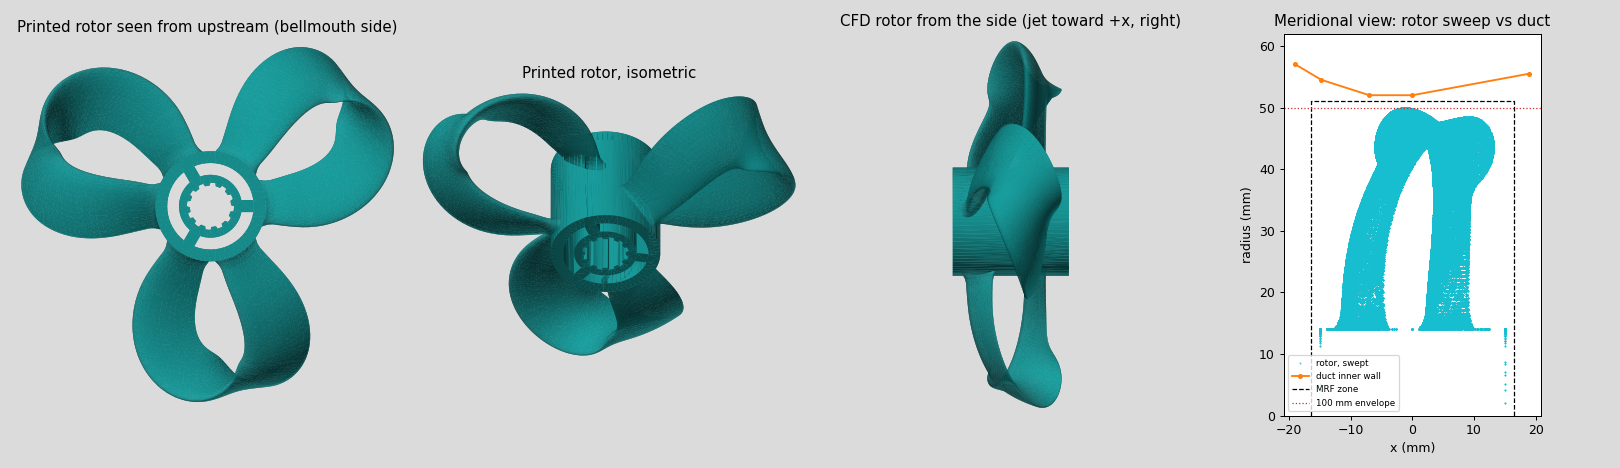
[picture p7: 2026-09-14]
projects/toroidal-rov-thruster/prototype1D_1B14_openFOAM/prototype1D_1B14_v2412/geometry/preview.png

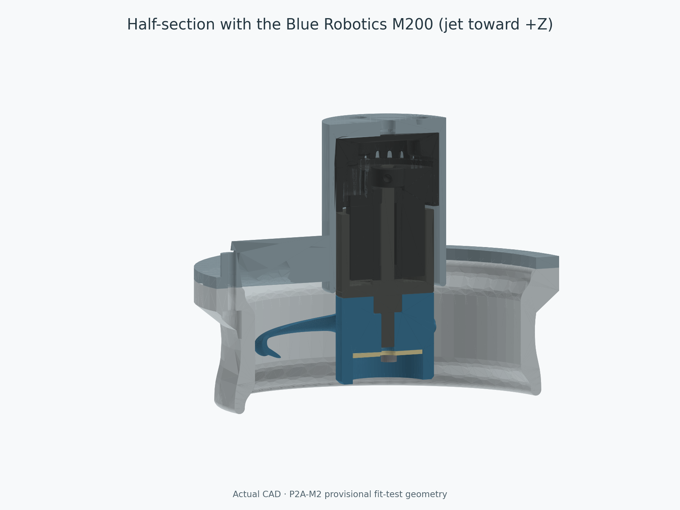
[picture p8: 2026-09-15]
projects/toroidal-rov-thruster/toroidal_rov_prototype2A/thruster_proto2A/previews/section.png

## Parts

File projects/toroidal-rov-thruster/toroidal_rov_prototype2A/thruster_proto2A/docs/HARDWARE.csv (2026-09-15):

item | quantity | category | nominal_description | status
Rotor | 1 | printed resin | One-piece three-loop rotor with M200 hub (collar counterbore; D-bore; 2 screw holes; 2 vent passages) | Resin process approval pending
Full duct | 1 | printed resin | Symmetric foil duct with faired rear flange and nut spot faces | Resin process approval pending
Motor support | 1 | printed resin | Flange ring + foil struts + flooded M200 shroud + rear plate + cable boss | Resin process approval pending
Hub fit coupon | 1 | printed resin | Three copies of the M200 hub interface and three M3 holes | Print before rotor
Blue Robotics M200 motor | 1 | purchased | Standard version with 1 m cable; can 36 x 29 mm; base 40 x 25.5 mm; Kv 470; 390 W at 16 V | Selected; vendor CAD in hardware/vendor
Clamp ring | 1 | machined or purchased metal (stainless) | 27 OD x 6 ID x 1.5 with 2x 3.3 holes on 19.05 PCD and 2x 4.5 vent holes on 21 PCD | Make to hardware/REFERENCE_clamp_ring.step
Rotor screws | 2 | purchased metal | M3 x 25 socket head cap screw (stainless) | 4 mm engagement into M200 rotor face (5 mm maximum); no threadlocker
Motor base screws | 4 | purchased metal | M3 x 8 socket head cap screw (stainless) | 5 mm engagement into M200 base inserts (6 mm maximum)
Duct-support bolts | 3 | purchased metal | M3 x 25 socket head cap screw | Check grip on the printed parts
Duct-support nuts | 3 | purchased metal | M3 nut (nylon-insert locking type recommended) | Locking method pending
Duct-support washers | 6 | purchased metal | M3 washers | Confirm bearing area on resin
Reversible brushless ESC | 1 | purchased | Bidirectional; rated for 24 A at 16 V or more | Not selected
Battery | 1 | purchased | M200 runs on 7-20 V; 16 V (4S) nominal | Voltage not selected
Cable penetrator | 1 | purchased | M10-6.5mm-LC (Blue Robotics' penetrator for the M200 cable) if the cable enters an enclosure | Routing not designed

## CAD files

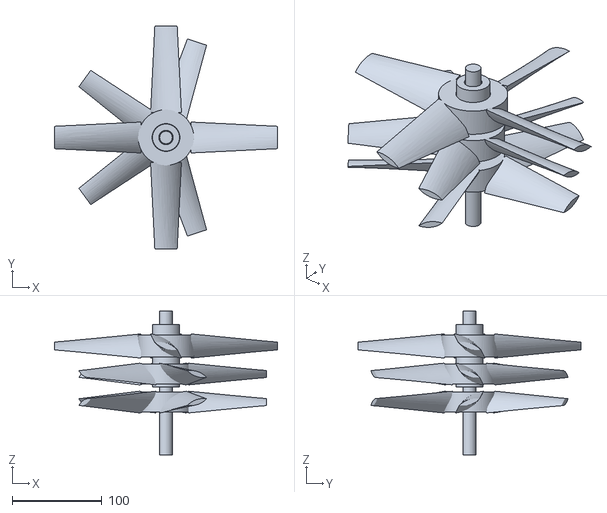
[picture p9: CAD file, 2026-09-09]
cad/underwater/contra-rotating/model.stl
248.5 x 248.5 x 160.0

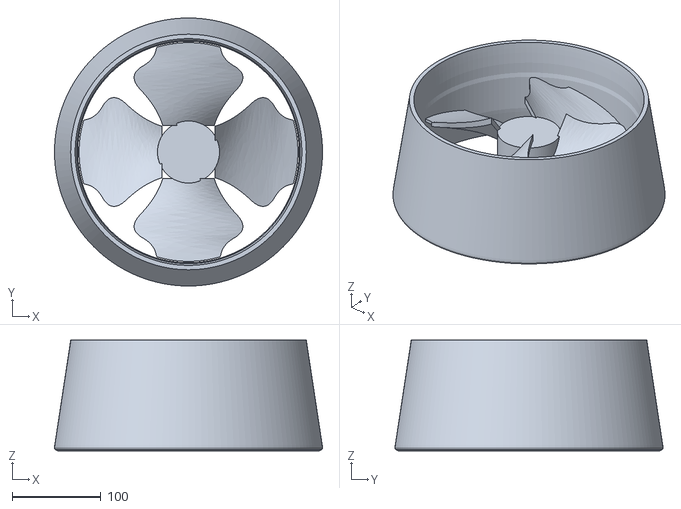
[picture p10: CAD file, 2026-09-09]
cad/underwater/ducted-kort/model.stl
302.5 x 302.5 x 125.0

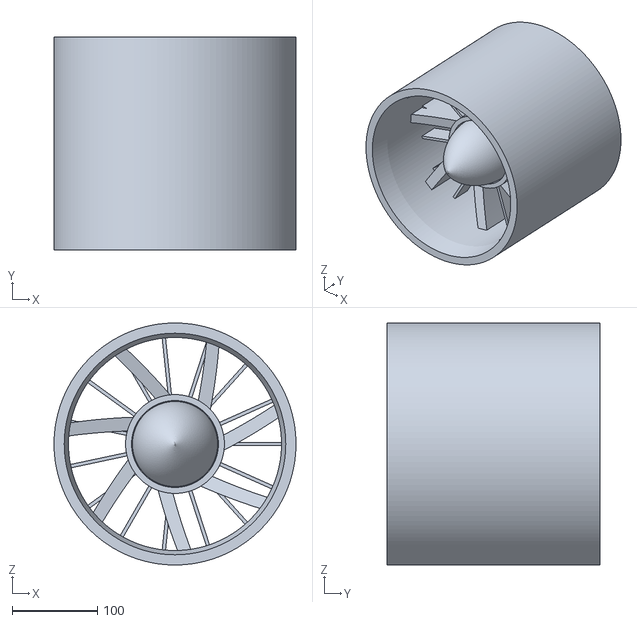
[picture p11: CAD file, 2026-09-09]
cad/underwater/pump-jet/model.stl
284.0 x 250.0 x 284.0

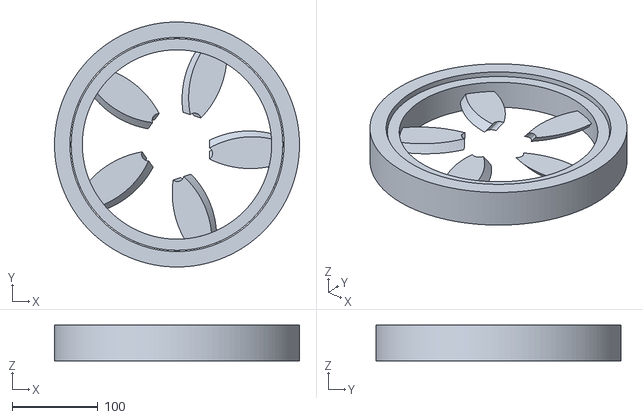
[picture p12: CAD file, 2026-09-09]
cad/underwater/rim-driven/model.stl
286.0 x 286.0 x 42.0

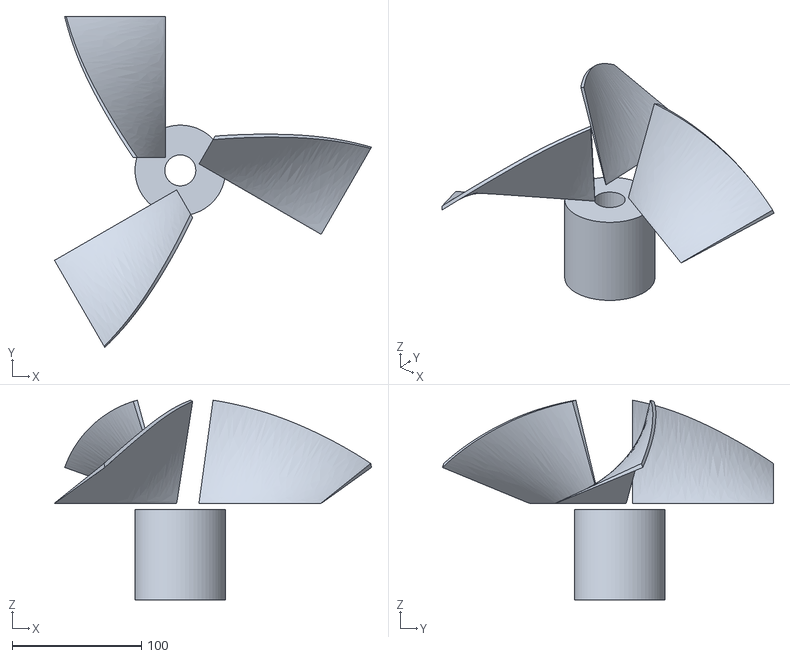
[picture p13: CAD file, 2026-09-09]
cad/underwater/supercavitating/model.stl
245.0 x 255.9 x 154.3

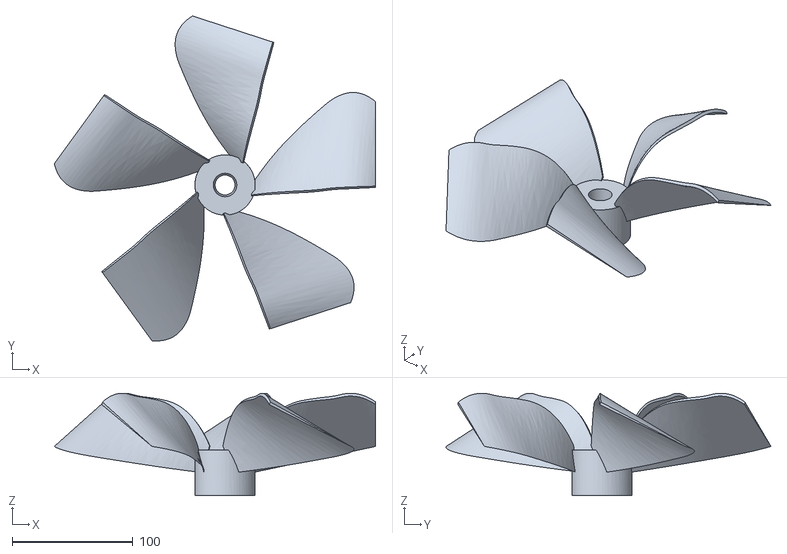
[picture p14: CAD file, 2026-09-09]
cad/underwater/surface-piercing/model.stl
266.7 x 269.6 x 85.0

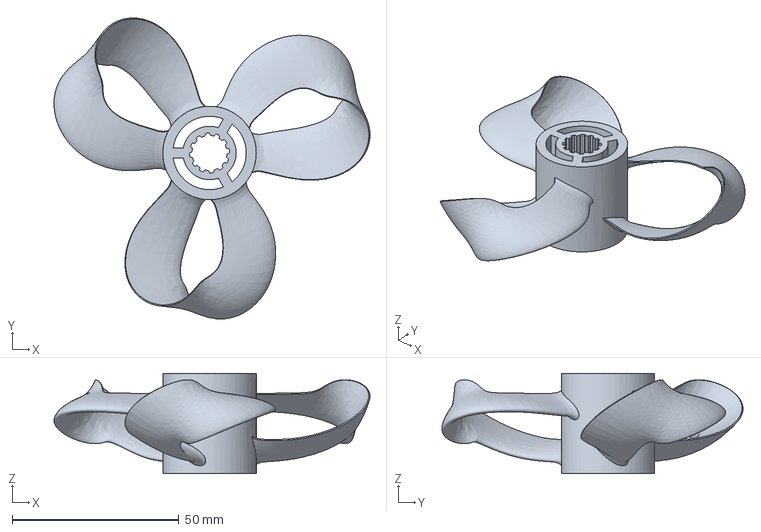
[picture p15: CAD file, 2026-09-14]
projects/toroidal-rov-thruster/prototype1D_1B14_openFOAM/prototype1D_1B14_v2412/geometry/rotor_1B14.step
94.7 x 90.2 x 30.0 mm

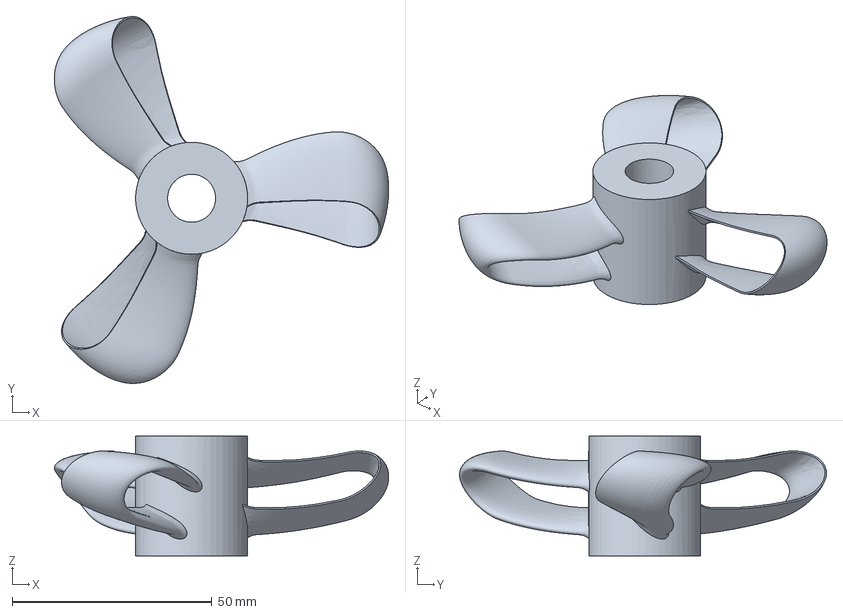
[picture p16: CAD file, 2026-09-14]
projects/toroidal-rov-thruster/prototype1D_1B14_openFOAM/prototype1D_1B14_v2412/results/designA_stacked_loops_L0/geometry/rotor_1B14.step
83.6 x 91.8 x 30.0 mm

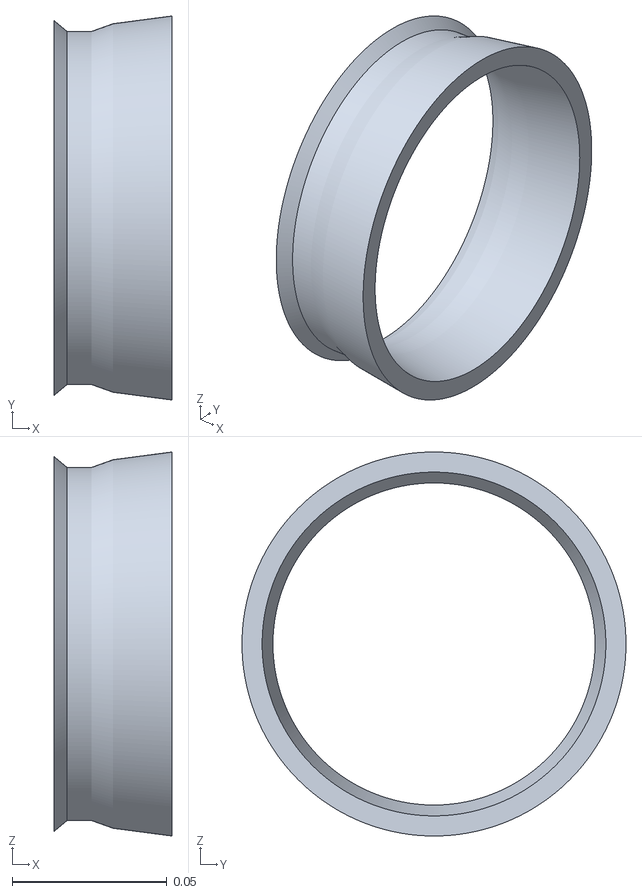
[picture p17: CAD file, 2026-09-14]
projects/toroidal-rov-thruster/prototype1D_1B14_openFOAM/prototype1D_1B14_v2412/geometry/duct_1B14.stl
0.038 x 0.124 x 0.124

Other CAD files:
projects/toroidal-rov-thruster/prototype1D_1B14_openFOAM/prototype1D_1B14_v2412/geometry/rotor_1B14.stl
projects/toroidal-rov-thruster/prototype1D_1B14_openFOAM/prototype1D_1B14_v2412/results/designA_stacked_loops_L0/geometry/rotor_1B14.stl

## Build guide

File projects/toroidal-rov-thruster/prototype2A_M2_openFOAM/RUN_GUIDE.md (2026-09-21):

# P2A-M2 CFD case — run guide

This case calculates bollard (still-water) thrust, torque and power for prototype 2A revision M2 at 3000 rpm, with OpenFOAM v2412. It is built from the 1B-14 case (`../prototype1D_1B14_openFOAM/prototype1D_1B14_v2412/`) and uses the same physics:
- steady rotating-zone (MRF) solver, `simpleFoam`;
- k-omega SST turbulence;
- seawater;
- open inlet, outlet and sides.

**What changed from 1B-14:**
- Two surfaces: `rotor` (spins) and `stator` (the duct, struts and motor pod, which do not spin).
- A bigger domain (5 D upstream, 10 D downstream, 5 D radius) and a refined wake region, as recommended after the design A run.
- Forward rotation is `omega -314.159265359`: the P2A rotor turns the opposite way to 1B-14.

## Folder layout

| Path | What it is |
|---|---|
| `geometry/` | `rotor_p2a.stl`, `stator_p2a.stl` (metres, axis +x), `cfd_geometry.json`, `preview.png` |
| `system/` | Mesh and solver settings. `blockMeshDict` and `snappyHexMeshDict` are generated from their `.template` files |
| `constant/` | `MRFProperties` (spin), `transportProperties` (water), `turbulenceProperties`; the mesh after meshing |
| `0.orig/` | Starting and boundary values; copied to `0/` when a run starts |
| `scripts/` | `configure_mesh.py`, `validate_geometry.py`, `render_cfd_geometry.py`, `convergence_report.py` |
| `results/` | Written-up results |
| `MESH_SPEC.yaml` | The mesh plan in one place |

## Step 1: make the geometry

The surfaces come from the prototype's CAD:

```bash
cd ../toroidal_rov_prototype2A/thruster_proto2A
python source/export_cfd.py
```

This writes `exports/cfd/` and copies the STLs into this case's `geometry/`. It builds a simplified CFD shape:
- the rotor hub is closed and extended to x = 17 mm;
- the flooded motor shroud is filled into a solid pod starting at x = 18 mm;
- holes, slots and the cable boss are left out.

To see where everything sits:

```bash
python3 scripts/render_cfd_geometry.py
```

This writes `geometry/preview.png`.

## Step 2: open an OpenFOAM shell

```bash
openfoam2412
cd <repo>/projects/toroidal-rov-thruster/prototype2A_M2_openFOAM
```

Your prompt changes. All commands below run inside this shell.

## Step 3: mesh

```bash
./Allclean          # removes any old mesh and logs
./Allmesh L0        # builds and checks the mesh; stops at the first failed check
```

What `Allmesh` does, in order:
1. `configure_mesh.py L0` fills the mesh templates: 16 mm background cells, 0.25 mm on the rotor, 0.5 mm on the stator, 1 mm around the rotor and 4 mm in the wake.
2. `validate_geometry.py` checks:
   - both STLs are closed, outward-facing and in metres;
   - the rotor fits in 100 mm and has at least 2 mm tip gap;
   - the rotating zone keeps 0.5 mm from every surface.
   It then copies the STLs to `constant/triSurface/`.
3. `surfaceCheck` runs OpenFOAM's own check of each STL, including self-intersection.
4. `blockMesh` builds the background box of cubes.
5. `surfaceFeatureExtract` finds the sharp edges to keep: trailing edges, lips, strut edges.
6. `snappyHexMesh` refines cells near the surfaces, cuts the solids out and snaps cells onto the surfaces. This is the slow step.
7. `topoSet` marks the cells inside the rotating zone (`mrfZone`).
8. `checkMesh` must report "Mesh OK".

The result for this case is in `results/P2A_M2_mesh_L0.md`: cells, quality, time and memory.

Each step writes a `log.<step>` file. If a step fails, read its log, fix the cause, then run `./Allclean` before `./Allmesh` again: steps whose log already exists are skipped.

## Step 4: short direction check (about 300 iterations)

Before a long run, check that the thruster pushes water the right way:

```bash
./Allsolve 300
python3 scripts/convergence_report.py --window 100 --batches 3
```

Look for these three things. The numbers won't be converged yet; only the signs matter.

| Quantity | Expected |
|---|---|
| Assembly force | Negative: thrust toward −x |
| Shaft power | Positive |
| Jet | "+x (bellmouth intake, as designed)" |

## Step 5: full run

```bash
./Allsolve          # 5000 iterations on 6 cores (system/decomposeParDict)
python3 scripts/convergence_report.py --write results/P2A_M2_L0_forward.md
```

Design A needed 2.9 s per iteration at 2 M cells on this laptop. Scale that by this case's cell count to estimate the run time; at about 3 M cells, expect 6–7 hours.

The report averages the last 3000 iterations. It gives thrust (rotor and stator), torque, shaft power, flow, minimum wall pressure (cavitation) and y+, and ends with a verdict:
- CONVERGED;
- STATISTICALLY STEADY (oscillating about a stable mean; design A ended here);
- NOT CONVERGED.

If it isn't converged at 5000 iterations, raise `endTime` in `system/controlDict` while the solver is still running.

## Step 6: reverse thrust

Edit `constant/MRFProperties` and change `omega -314.159265359` to `omega 314.159265359`. Then repeat step 5 and write the report to `results/P2A_M2_L0_reverse.md`.

## Signs and frames

- **Frames:** the design frame is mm with the axis along +Z; this case is metres with the axis along +x, (x, y, z)_OF = 0.001 (z, y, −x).
- **Forward:** the rotor turns about −x, counter-clockwise seen from the inlet. The jet goes toward +x and the thrust on the thruster toward −x.
- **Force output:** `postProcessing/rotorForces` and `statorForces` give the force of the water on each part. Thrust is the negative of the total x force.

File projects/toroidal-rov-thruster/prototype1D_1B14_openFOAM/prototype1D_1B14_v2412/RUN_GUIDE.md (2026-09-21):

# Running prototype 1B-14 on OpenFOAM v2412

A self-contained CFD case for the 1B-14 toroidal thruster at bollard (still water, 3000 rpm). The original `../prototype1D_1B14` is left unchanged.

## The geometry is regenerated, not recovered

The recovered `prototype1B_rotor.stl` was not a valid solid, so it cannot give meaningful results:
- its loop blades folded into themselves at the tip;
- the roots twisted and floated off the hub;
- every surface pointed inward;
- it measured 111 mm across.

`scripts/make_geometry.py` builds a new rotor from the same design parameters (`prototype1B_design.json`). This is a new parametric design that follows those parameters, not the recovered shape. [geometry/GEOMETRY_REPORT.md](geometry/GEOMETRY_REPORT.md) lists every parameter, every assumption, and the checks it passed.

| Design | Loops | Status |
|---|---|---|
| A: stacked legs | Legs one behind the other along the axis; closed in the front view | Meshed and solved (L0, 5000 iterations). Archived in [results/designA_stacked_loops_L0](results/designA_stacked_loops_L0), with [CHECKS.md](results/designA_stacked_loops_L0/CHECKS.md) |
| **B: front-opening loops** (current) | Each loop opens about 56° in the front view, with a round apex, like the reference toroidal rotor | Geometry and L0 mesh checked (Mesh OK, 2.01 M cells, shape kept within 0.06 mm); not yet solved. See [results/designB_mesh_L0.md](results/designB_mesh_L0.md) |

Design B's printed part (`geometry/rotor_1B14.step`) has a ring hub with 3 spokes and a splined bore. The spline dimensions are placeholders: confirm them against your shaft before printing. The CFD STL keeps a closed hub.

To see the shape, run `python3 scripts/render_geometry.py` and open `geometry/preview.png`.

Near-wall resolution: neither design has prism layers yet, and on design A 61% of the rotor area sat at y+ 5–30, where wall functions are least accurate. A mesh-only layer trial on design B is recorded in [results/layer_trial_L0.md](results/layer_trial_L0.md).

Force signs in the reports: axial forces keep their sign (negative = toward −x, which is thrust for a +x jet), and shaft power is −ω × rotor moment (must be positive).

## What the folders mean

| Folder | Holds |
|---|---|
| `geometry/` | Rotor and duct STLs for CFD (metres), rotor STEP for CAD/printing (mm), section table, geometry report |
| `0.orig/` | Starting values and boundary conditions (copied to `0/` before solving) |
| `constant/` | Physics: `MRFProperties` (3000 rpm spin), `transportProperties` (seawater); the mesh after meshing |
| `system/` | How to mesh and solve: `controlDict` (iterations, outputs), meshing dictionaries, `topoSetDict` (rotating zone) |
| `scripts/` | Geometry generator, geometry checks, mesh level setup, convergence report |

## Step 0: once per computer

```bash
sudo apt install paraview
```

## Step 1: open an OpenFOAM terminal

Do this in every new terminal:

```bash
openfoam2412
cd <repo>/projects/toroidal-rov-thruster/prototype1D_1B14_openFOAM/prototype1D_1B14_v2412
```

## Step 2: geometry (only when design parameters change)

The finished geometry is already in `geometry/`. To rebuild it (about 15 s):

```bash
python3 scripts/make_geometry.py
```

## Step 3: mesh (about 12 minutes, 3 GB RAM)

Tested result: 1.89 M cells, rotating zone 1.08 M cells, max skewness 3.42, max non-orthogonality 66.7, `Mesh OK.`

```bash
./Allclean
./Allmesh L0
```

`Allmesh` stops at the first failed check and prints what failed. Each step writes a `log.<name>` file.

| Step | Checks |
|---|---|
| `validate_geometry.py` | Units, closed outward surfaces, rotor inside 100 mm, at least 2 mm to the duct, rotating zone clear of rotor and duct |
| `surfaceCheck` | STLs closed, one piece each, not self-intersecting |
| `blockMesh`, `snappyHexMesh` | Background box, then cut out rotor and duct and refine around them |
| `topoSet` | Rotating zone (`mrfZone`) is not empty |
| `checkMesh` | Must print `Mesh OK.` |

Look at the mesh with `paraview case.foam`. Use Surface With Edges and a Slice through the axis.

## Step 4: check the flow direction (about 15 minutes)

Which way the water goes depends on the rotation direction, so check it before the long run:

```bash
./Allsolve 300
python3 scripts/convergence_report.py --window 100
```

Read the `Flow direction` line:

- "bellmouth intake ... as designed": go to step 5.
- "REVERSED": in `constant/MRFProperties`, change `omega 314.159265359` to `omega -314.159265359`, then repeat step 4.

## Step 5: baseline run (about 3 hours on 6 cores)

This laptop solves fastest on its 6 performance cores. More ranks land on the slower efficiency cores and hold every other rank back. Measured: 6 ranks 2.9 s per iteration, 12 ranks 5.1 s.

```bash
./Allsolve
```

`Allsolve` always starts from iteration 0 and runs 5000 iterations. While it runs, use another terminal (after `openfoam2412` and `cd`):

```bash
tail -f log.simpleFoam                              # live solver output
python3 scripts/convergence_report.py               # converged yet?
```

If the report says NOT CONVERGED at 5000 iterations, raise `endTime` in `system/controlDict` while the solver is still running; it picks up the change. Starting `./Allsolve` again would begin from 0.

## Step 6: record the baseline

```bash
python3 scripts/convergence_report.py --write BASELINE.md
```

The report gives one of three verdicts:

| Verdict | Meaning |
|---|---|
| CONVERGED | Thrust, torque and flow averaged over the last 500 iterations differ by < 0.5% from the 500 before and swing < 1% within them; every residual has dropped 1000× or stopped changing. |
| STATISTICALLY STEADY | The answer keeps oscillating, but about a fixed average: over the last 3000 iterations each average is known to within ±2% (95%), and every residual has stopped changing. Use the averages with their ± values. |
| NOT CONVERGED | Neither. Look at which line fails before trusting any number. |

Reported values are averages over the last 3000 iterations, with a 95% ± range. The first baseline (5000 iterations, 4 h 19 min on 6 cores) is recorded in [results/designA_stacked_loops_L0/BASELINE.md](results/designA_stacked_loops_L0/BASELINE.md).

## Reading the numbers

| Quantity | Meaning |
|---|---|
| Thrust | Force pushing the thruster, opposite the jet (+x jet gives thrust toward −x) |
| Torque | Twisting load on the shaft (N·m) |
| Shaft power | ω × torque, in W. The motor budget is 300 W electrical. |
| T/P | Thrust per watt: the main figure of merit for bollard thrust |
| Min wall pressure and cavitation margin | Lowest pressure on the rotor and on the duct, and how far it stays above the pressure where seawater boils (cavitates) at 1 m depth. "Min pressure anywhere" can be an artefact at the edge of the rotating zone, so use the wall values. |
| y+ | Wall cell size in viscous units. Large values are expected at L0; wall functions handle them. |

In ParaView, open `case.foam`, select the last time, colour by `p` or `U`, and slice along the axis to see the jet.

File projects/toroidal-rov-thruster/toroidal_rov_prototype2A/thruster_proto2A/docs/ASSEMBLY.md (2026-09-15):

# Fit-test assembly guide (P2A-M2, Blue Robotics M200)

Start with unpowered hand testing.

1. **Coupon first.** Print `hub_fit_coupon` in the rotor's resin, orientation, exposure and post-cure. Test each column on the real M200 rotor: the collar, the shaft and its flat. Test the M3 holes with the real screws. Transfer the chosen values to `collar_diameter_allowance`, `pilot_bore_allowance` and `screw_clearance_hole`, rebuild and recheck. See `COUPON.md`.
2. **Prepare the parts.** Remove supports and post-cure as the resin maker specifies.
   - Clear the collar counterbore, D-bore, both vent passages, the screw holes and the cable hole.
   - Inspect the loop closures, root flares and 0.5 mm trailing edges; don't sand the edges away.
   - The hub rear face must be flat: it seats on the M200 rotor face.
3. **Cable through the shroud.** From inside the shroud, push the free end of the M200 cable out through the radial cable hole and strain-relief boss.
4. **Motor into the support.**
   - Slide the M200 into the shroud from the front, base first, turning it so the cable lines up with the hole. The Ø40 base is a slide fit in the bore; don't force it.
   - Seat the base on the rear plate and fit 4× M3 × 8 socket head screws from the rear through the counterbores.
   - Turn the M200 rotor by hand: it must not touch the shroud (2.3 mm nominal gap).
5. **Rotor onto the motor.**
   - Line the hub's D-bore up with the shaft flat. The flat faces the cable side.
   - Slide the rotor on until the hub rear face sits flat on the M200 rotor face, with the collar inside its counterbore.
   - Put the metal clamp ring in the front recess with its two vent holes over the hub's vent passages.
   - Fit 2× M3 × 25 socket head screws into the M200 rotor face and tighten evenly until snug.
   - **No threadlocker:** Blue Robotics warns that most threadlockers attack the polycarbonate in their motors.
   - Resin under a clamp relaxes, so recheck the screws after the first soak.
6. **Duct.** Slide the duct over the rotor from the front until its rear flange meets the support's flange ring. Fit 3× M3 × 25 bolts from the rear through the strut bosses, with a washer under each head, and washers and nuts in the flange spot faces.
7. **Hand check.** Turn the rotor through several full revolutions with the assembly in different orientations.
   - Measure the tip gap (2 mm nominal), the axial gap to the shroud lip (2 mm) and the runout.
   - Nothing may touch the duct, struts, shroud, screws or cable.
   - Look through the vent passages: you should see the M200's vents.
8. **Direction.** For forward thrust the rotor must turn **counter-clockwise seen from the inlet** (the open front of the duct). If it spins the wrong way, swap any two of the three motor wires at the ESC. Water then leaves past the motor support.
9. **Service order.** Remove the duct (3 bolts), then the rotor (2 screws from the front), then the motor (4 screws from the rear).

## Load path

- **Torque:** M200 shaft flat → hub D-bore, plus the 2 clamped face screws → hub → loops.
- **Forward thrust (jet toward the support):** pulls the rotor away from the motor.
  - The 2 face screws carry it in tension into the M200 rotor.
  - The motor bearings carry it to the base, and the 4 base screws carry it into the rear plate, the struts, the duct flange and the ROV mount.
  - Thrust of about 35–40 N gives about 20 N per screw.
- **Reverse thrust:** presses the hub onto the rotor face and the base onto the rear plate.
- The collar only locates. The Blue Robotics T200 uses the same motor at up to 51 N forward and 40 N reverse at 16 V.

## Screw access

| Joint | Tool approach | Remaining check |
|---|---|---|
| Rotor to M200, 2× M3 × 25 | Axially through the duct inlet, or before fitting the duct | Head clearance in the recess |
| Duct to support, 3× M3 × 25 | Heads from the rear at the strut bosses; nuts at the front of the flange | ROV mount access to the nuts |
| M200 base to plate, 4× M3 × 8 | From the rear | Engagement ≤ 6 mm (5 mm as designed) |

No swept tool-access simulation has been done. Check access on the first print.

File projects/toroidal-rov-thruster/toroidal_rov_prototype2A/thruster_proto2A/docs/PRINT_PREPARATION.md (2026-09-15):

# Print preparation — resin (SLA/MSLA), conditional, not machine approved

The printer, resin and slicer are unconfirmed. No sliced project or exposure file exists, and the 3MFs hold geometry only.

## Approximate resin volume (solid parts, before supports)

| Part | Volume | Size (mm) |
|---|---|---|
| rotor | 27 cm³ | 82 × 92 × 30 |
| duct_full | 119 cm³ | 134 × 134 × 44 |
| motor_support | 45 cm³ | 134 × 134 × 59 |
| hub_fit_coupon | 36 cm³ | 82 × 30 × 16 |

Exact values are in `reports/build_report.json` and `reports/mesh_report.json`.

## Orientation candidates

Resin prints are pulled off the vat film layer by layer. Avoid large flat cross-sections parallel to the plate (high peel force) and cups that open toward the plate (suction). Tilting parts 20–45° is normal.

| Part | Candidate to inspect | Concerns |
|---|---|---|
| Rotor | Axis tilted about 30–45°, rear (motor) face away from the plate | Keep supports off the rear seating face, the collar counterbore, the D-bore and the trailing edges. Support the hub front rim and near the loop roots, and check every loop apex for islands. |
| Duct | Standing on edge or tilted about 20–30° | A flange-down ring has a large peel area; on a plate narrower than 134 mm it has to stand on edge. Keep supports off the inner throat surface. |
| Motor support | Tilted, with the shroud's open front **not** facing the plate | The shroud is a cup, so the cooling slots, cable hole and drain hole must vent during printing. Keep supports off the shroud bore (the M200 base slides in there) and off the rear plate's motor seat. |
| Coupon | The same tilt as the rotor hub axis | Only then do the measured bores transfer to the rotor. |

These are starting points to inspect in the slicer, not approved orientations. Each 3MF keeps +Z and only moves the part onto the plate; apply rotations in the slicer.

## Feature sizes to check

- **Loops:** 0.5 mm trailing edges; the thinnest section is at least 1.0 mm.
- **Hub:**
  - collar counterbore Ø11.2 × 6.3 mm;
  - Ø5.1 mm round bore and D-bore (flat 4.05 mm);
  - two Ø4.5 mm vent passages and two Ø3.3 mm screw holes;
  - clamp-ring recess Ø27.5 mm.
  - Resin shrinkage and over-cure make holes smaller: calibrate with the coupon.
- **Shroud bore:** Ø40.6 mm, a slide fit on the M200 base (Ø40 ±0.2). If it prints tight, adjust `support.base_slide_clearance` rather than sanding unevenly: this bore centres the rotor in the duct.
- **Duct:** 2 mm tip gap in the throat. Warped duct prints close this gap, so measure roundness after post-cure.
- **Support:** 2.5 mm shroud wall, 4 mm foil struts, 4 mm flange ring, 5 mm rear plate, Ø7 mm cable hole.

## Material notes

Use a tough, ABS-like or engineering resin. Wash and post-cure to the maker's instructions, because under-cured parts are weak and dimensionally unstable. Standard resins are brittle, absorb water and creep under sustained load. Treat these parts as fit-test and short wet-test parts, not for long submerged running.

## Mandatory slicer review

After choosing the real printer and resin, check:
- the mm scale and plate fit;
- islands and unsupported overhangs layer by layer, at the loop apexes, roots, trailing edges, strut tips, bolt bosses and cable boss;
- suction cups and trapped volumes;
- that every support can be removed without touching trailing edges, the hub rear face or the shroud bore.

Keep the slicer project in `slicer/`. `previews/rotor_layer_sections.png` shows geometric cross-sections only; it is not a slicer preview.

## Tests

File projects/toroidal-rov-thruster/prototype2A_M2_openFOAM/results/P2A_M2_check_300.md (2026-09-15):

# P2A-M2: 300-iteration direction check (L0)

Run 2026-09-15 with `./Allsolve 300` on the L0 mesh (`P2A_M2_mesh_L0.md`). Setup:
- steady MRF, k-omega SST, seawater, bollard (still water);
- 3000 rpm forward: `omega -314.159` about +x;
- 6 cores.

**Purpose:** confirm the thruster works the right way round before a long run. **The values are not converged and must not be used as results.**

## Direction checks (all passed)

| Check | Expected | Result |
|---|---|---|
| Assembly force | Negative x (thrust toward −x) | −31.9 N mean over the run; −30.0 to −32.5 N over the last 50 iterations |
| Shaft power −ω·Mx | Positive: the rotor drives the water | +155 W (last 50 iterations) |
| Jet | +x, water entering the front bellmouth | +15.5 L/s through the rotor, consistent with the force |

## How the values were moving (provisional)

| Iterations | Thrust (rotor + stator) | Torque | Shaft power | Flow | Rotor min wall pressure |
|---|---:|---:|---:|---:|---:|
| 151–200 | 25.9 N (20.8 + 5.1) | 0.487 N·m | 153 W | 13.5 L/s | −196 kPa |
| 201–250 | 27.0 N (20.9 + 6.2) | 0.501 N·m | 157 W | 14.5 L/s | −210 kPa |
| 251–300 | 31.5 N (24.0 + 7.5) | 0.493 N·m | 155 W | 15.5 L/s | −197 kPa |

- **Trend:** thrust and flow were still rising at iteration 300. Torque was already nearly steady at about 0.49–0.50 N·m.
- **For orientation only:** the converged 1B-14 design A run gave 27.0 N, 0.451 N·m, 142 W and 16.0 L/s. It used a different rotor, domain and mesh.
- **Residuals:** p dropped 4.6 decades; U 1.9–2.2; k 2.5; omega 1.5. The turbulence solver printed "bounding k" warnings up to iteration 292. That is common while the flow develops; check it has stopped in the long run.
- **Time:** 4.43 s per iteration on 6 cores, so 5000 iterations take about 6.2 hours.

## Things to watch in the full run

- **Cavitation:** the lowest rotor wall pressure was about −200 kPa gauge. At 1 m depth that is far below vapour pressure; the convergence report says it clears below about 12 m. Design A's converged value was −141 kPa. This L0 value is unconverged and uses wall functions, so it only shows where to look.
- **Motor torque:** the rotor absorbs about 0.5 N·m at 3000 rpm. Check this against the M200's real capacity once converged. Blue Robotics' simulated 0.5 N·m "stall torque" does not match the T200's measured 390 W at 3600 rpm, so it is not a firm limit.

## Next step (needs a go-ahead)

Run the full forward solve: `./Allsolve` (5000 iterations, about 6.2 h). Then run `python3 scripts/convergence_report.py --write results/P2A_M2_L0_forward.md`.

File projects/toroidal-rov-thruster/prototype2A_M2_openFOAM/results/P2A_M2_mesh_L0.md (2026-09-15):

# P2A-M2: L0 mesh check

Meshed 2026-09-15 with `./Allmesh L0` (OpenFOAM v2412). No flow solve has been run yet. Geometry: `geometry/rotor_p2a.stl` and `geometry/stator_p2a.stl` from the prototype's `source/export_cfd.py`. Layout: `geometry/preview.png`.

## Geometry checks (all mandatory, all passed)

| Check | Result |
|---|---|
| `validate_geometry.py` | Rotor radius 49.91 mm (limit 50); duct throat 103.97 mm; tip gap 2.13 mm |
| Rotating zone | r = 51 mm, x = −15.0…17.5 mm: 1.09 mm to the rotor tip, 0.98 mm to the duct, 0.50 mm to the motor pod |
| `surfaceCheck` rotor | Closed, 1 part, not self-intersecting |
| `surfaceCheck` stator | Closed, 1 part, not self-intersecting (only after the struts were lofted; see below) |
| `topoSet` | `mrfZone` 991,054 cells |

## Mesh quality (`checkMesh`: Mesh OK)

| Quantity | P2A-M2 | 1B-14 design B (for comparison) |
|---|---:|---:|
| Domain | 1.5 × 1.0 × 1.0 m (5 D / 10 D / 5 D) | 0.6 × 0.4 × 0.4 m |
| Background cell | 16 mm | 8 mm |
| Cells | 2,475,440 | 2,010,954 |
| Hexahedra / prisms / polyhedra | 2,151,413 / 78,996 / 244,874 | 1,719,508 / 49,526 / 241,861 |
| Max non-orthogonality | 69.9 (average 9.2) | 62.1 |
| Max skewness | 3.56 | 3.66 |
| Max aspect ratio | 9.9 | — |
| Rotor / stator patch faces | 156,624 / 216,032 | 189,673 (rotor) |
| Prism layers | none | none |
| Meshing time | 19.0 min (refine 4.4, snap 14.2) | 14.1 min |
| Peak memory | 3.6 GB | — |

Cells per refinement level: 0: 359,448 · 1: 7,808 · 2: 39,634 · 3: 49,243 · 4: 406,557 · 5: 964,235 · 6: 648,515. Level 6 (0.25 mm) is the rotor surface, level 5 (0.5 mm) the stator surface and level 4 (1 mm) the rotor region. The wake region is level 2 (4 mm) and level 0 (16 mm) the far field.

Max non-orthogonality sits just under snappyHexMesh's limit of 70. That is acceptable for the solver with `nNonOrthogonalCorrectors 1` (`system/fvSolution`), but refining further may push faces past it. Watch this value if levels change.

## Problems found and fixed before this mesh passed

1. **A parallel shell command changed the working directory**, so the first launch looked for `./Allclean` in the wrong folder. Background commands now use absolute paths.
2. **The stator failed `surfaceCheck`**, with 150–190 points on one strut. The extruded struts tessellated into full-span triangles about 0.01 mm wide (aspect ratio up to 2700). OpenFOAM's check flagged these, and how many it flagged depended on how the surface lined up with the axes. Splitting long edges made it worse. Lofting each strut through 9 identical sections, as the rotor blades are built, fixed it.
3. **Starting each strut exactly at the flange ring's front plane** made the ring fail to fuse. The struts now start 0.2 mm behind it.

## Not checked yet

- How closely the snapped rotor patch follows the STL. On design B the snapped mesh stayed within 0.06 mm of the geometry; this case has not been compared.
- The wake region is 4 mm cells, twice as fine as design A's wake but still coarse for the swirl. Decide after the first solve.
- No mesh-independence study (L1/L2).

## Next step (needs a go-ahead)

`./Allsolve 300`, then `python3 scripts/convergence_report.py --window 100 --batches 3`, to confirm thrust toward −x, positive shaft power and a +x jet. Then the full 5000-iteration forward run. The 300-iteration check measured 4.43 s per iteration on 6 cores, so that is about 6.2 hours. See `RUN_GUIDE.md` and `P2A_M2_check_300.md`.

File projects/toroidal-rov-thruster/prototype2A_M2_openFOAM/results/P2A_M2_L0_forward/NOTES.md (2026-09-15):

# P2A-M2 forward L0 run: notes

- **Run:** `./Allsolve 5000` on the L0 mesh (`../P2A_M2_mesh_L0.md`), 6 cores, 4.1 s per iteration.
- **Stopped at iteration 4467** on 2026-09-15, by choice, after about 5 h 10 min. `stopAt writeNow` wrote the fields, and `reconstructPar` put them in the case's `4467/` folder.
- **This folder:** `REPORT.md` (from `scripts/convergence_report.py`), `history.png`, `postProcessing/` (force, flow, pressure and residual histories), `log.checkMesh`, the mesh spec and the physics settings. The fields themselves (`4467/`, `processor*/`) stay in the case and are not in git.

## Result (averages over iterations 1461–4460)

| Quantity | P2A-M2 | 1B-14 design A (L0 baseline) |
|---|---:|---:|
| Thrust, total | **29.1 ± 0.6 N** | 27.0 ± 0.5 N |
| — rotor / duct and support | 17.9 / 11.3 N | 18.4 / 8.6 N |
| Rotor torque | 0.413 ± 0.010 N·m | 0.451 N·m |
| Shaft power | 130 ± 3 W | 142 W |
| Thrust / power | 0.225 N/W | 0.191 N/W |
| Flow through rotor | 18.1 L/s | 16.0 L/s |
| Lowest rotor wall pressure | −180 kPa (clears cavitation below about 8 m) | −141 kPa (below about 4.2 m) |
| y+ rotor mean / max | 30 / 159 | 35 / 157 |

The ± values give the uncertainty of each average, not the size of the swings.

## How to read it

- **Convergence:** the verdict is NOT CONVERGED, and 5000 iterations would likely have given the same verdict.
  - Thrust and flow average out well: ±2% and ±0.6%, with drift under 0.4%.
  - Torque still drifts 2.3% between windows, above the 1% limit.
  - The steady-MRF solution swings about its mean (thrust peak-to-peak 38%), as design A's did.
  - Residuals have been flat for thousands of iterations, and "bounding k" warnings stopped after iteration 3815.
  - Treat the table as statistically steady mean values with a few per cent uncertainty on torque.
- **Against design A:** P2A-M2 gives about 8% more thrust for 8% less shaft power, and about 18% better thrust per watt. The duct and support carry more of the thrust (39% vs 32%). The cases differ, so this is not a clean comparison:
  - rotor (true helix at P/D 0.75, not P/D 0.58);
  - duct (104 mm throat, symmetric foil);
  - a motor pod and struts in the jet;
  - a larger domain (5 D / 10 D / 5 D, compared with design A's 2 D / 4 D / 2 D, where the jet left through the sides);
  - a refined wake.
- **Target:** 35 N is not reached at 3000 rpm.
  - The torque (0.41 N·m) and power (130 W) leave headroom on the M200, which is rated 390 W electrical at 16 V.
  - A higher speed is the likely route to 35 N. As a rough scaling, thrust goes with rpm² and power with rpm³, so about 3300 rpm and 170–180 W at the shaft. Confirm with a run at that speed.
- **Cavitation:** the lowest rotor pressure (−180 kPa gauge, worst −250) sits at the loop apex. At 3000 rpm and shallow depth this predicts vapour bubbles; running faster makes it worse. L0 wall functions only indicate where the suction peak is, but it is the main design risk to act on: lighter loading at the apex, or a higher `closure_t_c` or chord there.

## Not done

- Reverse run (`omega +314.159`).
- Mesh independence (L1), prism layers, and a check of how closely the snapped rotor follows the STL.
- Field pictures (ParaView is not installed); `4467/` holds the fields for later.

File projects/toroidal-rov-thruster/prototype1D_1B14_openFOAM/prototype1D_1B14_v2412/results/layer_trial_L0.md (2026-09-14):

# Prism-layer trial on the design B L0 mesh (mesh only, no solve)

Run 2026-09-14 on a copy of the design B L0 mesh. The main case mesh has no layers and was not changed. Inputs and logs are in [layer_trial_L0/](layer_trial_L0/): `snappyHexMeshDict.layers`, `layer_trial.sh`, `log.snappyLayers.gz`, `log.checkMesh`.

## Why

- Design A had no prism layers, and 61% of the rotor area sat at y+ 5–30, the range where wall functions are least accurate.
- Viscous forces make up 18% of the rotor torque, so near-wall resolution matters for torque and power.
- The friction velocity implied by design A was median 0.22 m/s and 95th percentile 0.65 m/s. Putting the first cell centre at y+ ≈ 1 needs a first layer of about 10 µm.

## Settings

`snappyHexMesh -dict system/snappyHexMeshDict.layers -overwrite` with `castellatedMesh false; snap false; addLayers true;`. This adds layers to the existing snapped mesh.

| Setting | Value |
|---|---|
| Layers on rotor and duct | 12 |
| First layer thickness | 10 µm (`firstLayerThickness 1e-5`, `relativeSizes false`) |
| Expansion ratio | 1.2 |
| Target stack | 0.40 mm total; last layer 74 µm under 250 µm rotor faces |
| Layer controls | featureAngle 60, maxThicknessToMedialRatio 0.3, nLayerIter 50, nRelaxedIter 20 |
| Quality controls | as the main mesh, relaxed maxNonOrtho 75 |

## Results

| Quantity | Result |
|---|---|
| Run time / peak memory | 31.7 min / 7.1 GB |
| Cells | 2,010,954 → 3,837,513 (+91%) |
| Wall faces with layers | 278,500 of 301,711 (92.3%); **23,211 faces (7.7%) without layers** |
| Layer cells added | 1.83 M of 3.62 M for full stacks (50%) |
| Rotor: mean layers / thickness | 6.25 of 12 / 0.314 mm (79.8% of target) |
| Duct: mean layers / thickness | 5.73 of 12 / 0.337 mm (86% of target) |
| snappyHexMesh final check | **50 faces fail its quality controls**: 39 with non-orthogonality > 70, 11 with face-decomposition tet quality < 1e-20 |
| `checkMesh` | Mesh OK; max non-orthogonality 74.6; max aspect ratio 65; max skewness 3.66 |

## Expected y+ (estimate: design B has not been solved)

These estimates use design A's friction velocity. A solve is needed to confirm them.

| Wall faces | First cell centre | y+ at median u_τ | y+ at P95 u_τ | y+ at the apex hot spot (u_τ ≈ 1.3 m/s) |
|---|---|---:|---:|---:|
| Full 12-layer stack | 5 µm | ≈ 1.0 | ≈ 3 | ≈ 6 |
| Reduced stack, e.g. 6 layers filling 0.31 mm at ratio 1.2 (first layer ≈ 30 µm) | ≈ 15 µm | ≈ 3 | ≈ 9 | ≈ 19 |
| No layers (7.7% of faces) | 125 µm | ≈ 24 | ≈ 77 | ≈ 157 |

## Assessment

The layers work on most of the wall but are **not yet good enough for a production run**:

- **Coverage.** About half the layer cells are missing, and 7.7% of wall faces have none. Reduced and missing stacks leave part of the surface in the buffer layer again, so the uncertainty in viscous torque shrinks but does not go away.
- **Quality.** 50 faces fail snappyHexMesh's own criteria. With non-orthogonality up to 74.6, the solver would need `nNonOrthogonalCorrectors 2`.
- **Cost.** A layered solve would have about 3.8 M cells: roughly 2× the time per iteration (about 6 s on 6 cores against 3.1 s for design A), and the thin wall cells usually slow convergence. 5000 iterations would take about 8–10 hours on this laptop, which is a long run, so it was not attempted. Solver memory, about 4 GB, fits.

## Recommended next layer settings (not yet tested)

1. **Aim for y+ 1–3 rather than ≤ 1:** 8 layers, first layer 20 µm, expansion ratio 1.25 (about 0.3 mm total). That means fewer collapses and about 1.2 M extra cells instead of 1.8 M. The Spalding and omega wall functions stay valid through y+ ≈ 1–5.
2. **Let layers wrap trailing edges and the apex:** `featureAngle 130`, `maxThicknessToMedialRatio 0.5`, `nSmoothNormals 5`.
3. **Add the layers in the full snappyHexMesh run** (castellate, snap, then layers) instead of afterwards, and write `writeFlags (layerFields)`. That lets you check the `nSurfaceLayers` field in ParaView and see exactly where layers are missing.
4. **Solve and check:** add `nNonOrthogonalCorrectors 2` to the solver settings, then check y+ and layer coverage after about 500 iterations before committing to a full run.

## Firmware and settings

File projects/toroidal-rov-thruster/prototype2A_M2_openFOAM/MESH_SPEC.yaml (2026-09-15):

case: P2A-M2
geometry_source: ../toroidal_rov_prototype2A/thruster_proto2A/source/export_cfd.py
units: SI
axis: [1, 0, 0]
origin: [0, 0, 0]
rotation:
  rpm: 3000
  omega_rad_s: -314.159265359   # forward: about -x (design -Z); reverse: +314.159265359
geometry:
  rotor: geometry/rotor_p2a.stl      # rotating body: hub + loops, closed, extended to x = 17 mm
  stator: geometry/stator_p2a.stl    # duct + struts + ring + solid motor pod
  rotor_radius_max_m: 0.0500
  duct_throat_diameter_m: 0.104
  rotor_duct_clearance_min_m: 0.0020
  simplifications:
    - flooded motor shroud filled into a solid pod; cooling slots, cable boss and holes left out
    - 1 mm axial gap between the rotating body (x <= 17 mm) and the pod (x >= 18 mm)
mrf_zone:
  radius_m: 0.051
  x_min_m: -0.0150
  x_max_m: 0.0175
  margin_min_m: 0.0005
domain_bounds_m:
  x: [-0.5, 1.0]
  y: [-0.5, 0.5]
  z: [-0.5, 0.5]
mesh_levels:
  L0: {base_cell_m: 0.016, rotor_level: 6, stator_level: 5, rotor_region_level: 4, wake_region_level: 2}
  L1: {base_cell_m: 0.012, rotor_level: 6, stator_level: 5, rotor_region_level: 4, wake_region_level: 2}
  L2: {base_cell_m: 0.008, rotor_level: 6, stator_level: 5, rotor_region_level: 4, wake_region_level: 2}
refinement_regions:
  rotorRegion: {x_m: [-0.020, 0.022], radius_m: 0.056}
  wakeRegion: {x_m: [-0.050, 0.200], radius_m: 0.060}
layers: none (addLayers false)
cell_target_L0: about 3 M; above 3.5 M shrink the domain to 3 D / 8 D / 3 D
quality_acceptance:
  check_mesh: "Mesh OK."
  max_non_orthogonality: 70
  max_internal_skewness: 4
  max_boundary_skewness: 20
  min_volume: 1.0e-18
convergence_acceptance:
  window_iterations: 500
  mean_change_percent: 0.5
  peak_to_peak_percent: 1.0

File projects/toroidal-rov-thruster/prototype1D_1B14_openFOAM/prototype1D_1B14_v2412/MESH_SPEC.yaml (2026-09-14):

case: 1B-14
units: SI
axis: [1, 0, 0]
origin: [0, 0, 0]
geometry:
  source: geometry/ (built by scripts/make_geometry.py, checked by scripts/validate_geometry.py)
  rotor_radius_max_m: 0.0500
  duct_throat_diameter_m: 0.104
  rotor_duct_clearance_min_m: 0.0020
mrf_radius_m: 0.051
mrf_x_min_m: -0.0165
mrf_x_max_m: 0.0165
mrf_margin_min_m: 0.0005
domain_bounds_m:
  x: [-0.20, 0.40]
  y: [-0.20, 0.20]
  z: [-0.20, 0.20]
mesh_levels:
  L0: {base_cell_m: 0.008, rotor_level: 5, duct_level: 4, region_level: 3}
  L1: {base_cell_m: 0.006, rotor_level: 6, duct_level: 5, region_level: 3}
  L2: {base_cell_m: 0.004, rotor_level: 7, duct_level: 6, region_level: 3}
layers:
  first_layer_m: 0.000020
  count: 12
  expansion_ratio: 1.20
quality_acceptance:
  check_mesh: "Mesh OK."
  max_non_orthogonality: 70
  max_internal_skewness: 4
  max_boundary_skewness: 20
  min_volume: 1.0e-18
convergence_acceptance:
  window_iterations: 500
  mean_change_percent: 0.5
  peak_to_peak_percent: 1.0

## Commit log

2026-09-08 SETUP: aerial propeller designs
2026-09-08 Add underwater_designs.md with marine propeller design catalog
    Mirrors aerial_designs.md's format to cover the popular underwater/
    marine propeller design types (fixed-pitch, controllable-pitch, ducted/
    Kort nozzle with pump-jet, contra-rotating, surface-piercing, skewed
    blade, Voith Schneider), and links it from README.md.
    Claude-Session: https://claude.ai/code/session_01L5mNMq8h9SrNEi6zZrnw2m
2026-09-08 Add CAD build briefs for the aerial and underwater designs
    Each design in aerial_designs.md and underwater_designs.md gets a
    self-contained brief under cad/ describing what to model, its parameters,
    how to build it and when it is done, so a CAD agent can execute one
    without further context. Shared conventions and the blade loft pipeline
    are stated once per file so each brief only records its deviations.
    Prompts only — no models are built yet.
    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
2026-09-08 Correct design claims and add current propeller designs
    Corrections, each checked against a source:
    - Coaxial contra-rotating did not "double thrust" — the lower rotor runs
    in the upper's wake and the pair falls well short of 2x
    - Toroidal was claimed "clearly quieter"; recent measurements show it
    redistributes tonal noise and costs torque
    - Folding blade linked a variable-pitch product
    - Ducted fan described as "speed-limited" rather than losing duct benefit
    with forward speed
    - Ducted fan and pump-jet stator counts used coprimality instead of the
    Tyler-Sofrin cut-off rule (V >= 2Z)
    - Pump-jet mandated a post-swirl stator for a submarine, which is the
    torpedo arrangement; submar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
2026-09-08 Add toolchain resources and fix CAD guidance
    README gained the resources the build briefs depend on but never named:
    CadQuery, OpenVSP, PropCad, the B-series generator and the UIUC airfoil
    coordinate database for geometry; XFOIL, XROTOR, QPROP, JBLADE, the ITTC
    open water procedure and trimesh for analysis and checking.
    CAD guidance corrections:
    - Frame said "right-hand rotation" while also fixing thrust direction;
    those are not independent, so it now pins the rotation vector and
    requires the twist sign to be verified against it on the model
    - Both files told the agent to "wrap" a section onto a cylinder; no such
    operation exists, so it now specifies the coordinate transform
    - Opposit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
2026-09-09 Add: underwater cad models
    [model.stl]
2026-09-10 Add source geometry for every CAD design
    Name and file the six built STLs at cad/<domain>/<slug>/model.stl and review
    each against its brief. Add a source-geometry.md manifest per design (13
    underwater, 11 aerial) recording the geometry data it needs.
    Underwater data is now complete: real tables where they could be obtained
    (19A duct ordinates, Ka sections, DTMB 4119, PPTC VP1304, DTMB 4381-4384),
    and parametric tables generated from each brief's own parameters where no
    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
    [blade-planform.csv, blade-schedule.csv, cleaver-planform.csv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]
2026-09-10 Add source geometry for the aerial designs
    [apc-10x5e.csv, bearing-bores.csv, bend-path.csv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]
2026-09-11 Add datums, hub and camber; build ducted-kort from its tables
    Add cad/CONVENTIONS.md defining the pitch line, generator line, rake and
    camber conventions the briefs leave implicit, and repeat them as a header
    block in every geometry CSV so a table can be read on its own. Add hub
    tables, root fillet schedules and camber columns; rim-driven correctly has
    no hub.
    Rewrite both design catalogues: entries now link into cad/, say when to use
    each design and when not to, carry typical ranges, and mark model links as
    authoritative or third-party.
    Add cad/tools/build_ducted_kort.py, the first model generated from the
    committed tables rather than by hand. Nozzle outer radius 151.338 against
    the 19A p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
    [apc-10x5e.csv, bearing-bores.csv, bend-path.csv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]
2026-09-14 Add toroidal ROV 1B-14 thruster CFD case for OpenFOAM v2412
    - Add the prototype 1B design package (STLs, design notes, 27-case DOE)
    and the original 1B-14 OpenFOAM case template.
    - Add prototype1D_1B14_v2412, a copy of the case that runs on
    OpenFOAM v2412:
    - Allmesh converts the STLs from mm with a z axis to m with an x axis,
    then builds and checks the mesh.
    - Allsolve runs simpleFoam with the rotating (MRF) zone in parallel.
    It won't start before meshing finishes and clears old runs first.
    - Allclean removes the mesh, results and logs.
    - Replace v2412-invalid entries: symmetryPlane farfield, residuals
    function object, features syntax, potentialFoam and setFields.
    -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
    [CFD_DOE_27.csv, prototype1B_duct.stl, prototype1B_outer_domain.stl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]
2026-09-14 Regenerate 1B-14 rotor geometry, archive L0 baseline, mesh loop design B
    The recovered prototype1B rotor STL is not a valid solid (folded loop tips,
    1604 self-intersecting triangle pairs, inward normals, 111 mm envelope), so
    the case now builds its own geometry and refuses to mesh unchecked input.
    [duct_1B14.stl, rotor_1B14.step, rotor_1B14.stl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]
2026-09-15 Add toroidal ROV prototype 2A (M2, Blue Robotics M200) and its CFD case
    Prototype 2A CAD package (toroidal_rov_prototype2A/thruster_proto2A):
    - Rebuild the P2A-M0 rotor: constant P/D 0.75 on a true helix, NACA
    sections, apex solved to the 100 mm envelope, shared-knot loft.
    - Fit the Blue Robotics M200: hub seats on the rotor face with 2x M3,
    D-flat drive, collar counterbore and vent passages. The shroud bore
    centres the motor base, the cable leaves radially and the base takes
    4x M3x8 screws.
    - Symmetric foil duct with a 2 mm tip gap, lofted foil struts, hub fit
    coupon and resin print notes.
    - Align and cross-check the vendor M200 STEP against the parameters
    (source/motor_step.py)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
    [CFD_DOE_27.csv, HARDWARE.csv, REFERENCE_M200_rotating.step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]
2026-09-15 Archive P2A-M2 forward L0 CFD run (stopped at iteration 4467)
    - 29.1 N thrust (rotor 17.9 N, duct + support 11.3 N), 0.413 N m,
    130 W shaft, 0.225 N/W, 18.1 L/s at 3000 rpm; averages over the last
    3000 iterations. Torque still drifts ~2%, verdict not converged.
    - Rotor minimum wall pressure -180 kPa: cavitation at the loop apex
    shallower than about 8 m.
    - Report, notes, history plot and postProcessing histories in
    results/P2A_M2_L0_forward; roadmap updated.
    [MESH_SPEC.yaml]
2026-09-21 Make this a reference repository
    Keep the shape that was working -- a scannable index, the two design
    references, the build briefs -- and add what it was missing: a licence,
    a formula sheet, provenance the tables can be checked against, and a
    clone that is not mostly generated binaries.
    Reference
    - README.md keeps its original flat shape (designs, CAD prompts,
    geometry creation, data and tools) with the link annotations intact,
    plus a short "in this repo" section and three lines on how to read the
    data labels. No status banner, no quickstart.
    - formulas.md, new: the working equations with the datum each assumes --
    ratios and Ae/Ao, face-pitch angle, advance ratio, Kt/Kq/eta, tip
    s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
    [HARDWARE.csv, REFERENCE_M200_rotating.step, REFERENCE_M200_rotating.stl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]
